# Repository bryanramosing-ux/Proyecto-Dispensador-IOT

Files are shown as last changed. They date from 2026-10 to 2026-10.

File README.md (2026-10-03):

# Dispensador inteligente de alimento para mascotas mediante IoT, visión artificial y energía solar

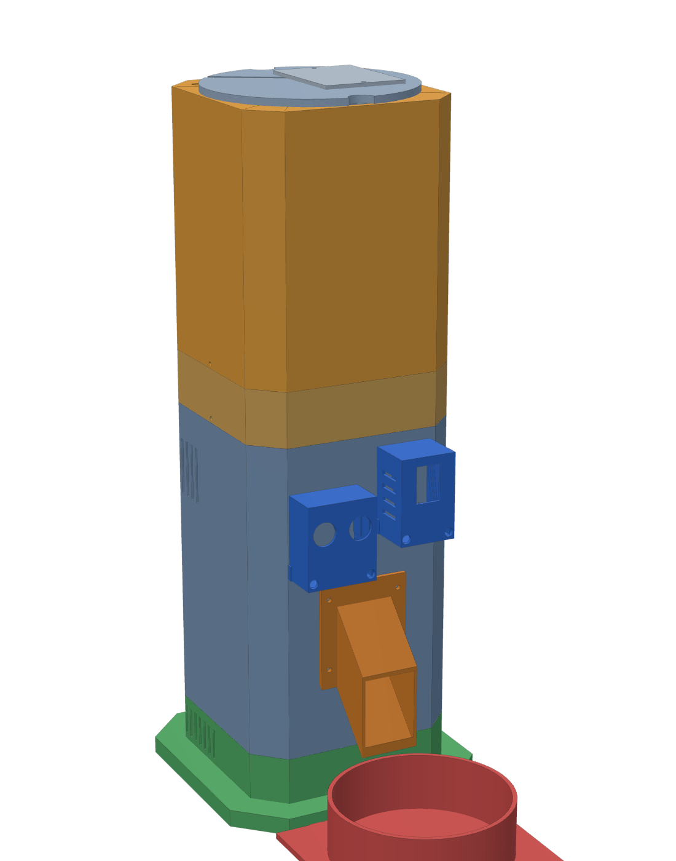
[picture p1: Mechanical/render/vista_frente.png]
Torre ensamblada


Proyecto universitario para feria de informática. Este repositorio contiene **todo** lo necesario para
construirlo y probarlo: firmware del ESP32 y de la ESP32-CAM, servidor de visión en Python + OpenCV,
22 piezas STL paramétricas listas para la **Elegoo Neptune 4 Plus**, [manual de armado](Documentation/manual_armado/Manual_de_Armado.md)
([PDF](Documentation/manual_armado/Manual_de_Armado.pdf)), un **[video de funcionamiento y armado](Documentation/video)**
(≈ 7 min, narrado y subtitulado), esquema eléctrico completo, cálculo energético, procedimientos de calibración y plan de
pruebas.

> **Cómo se elaboró (técnica ROL – TAREA – CONTEXTO).**
> **ROL:** equipo de ingeniería electrónica, sistemas embebidos/IoT, visión artificial, mecánica/diseño 3D,
> arquitectura de software y asesoría académica. **TAREA:** auditar el planteamiento inicial, corregirlo donde
> no era físicamente correcto y entregar un sistema construible. **CONTEXTO:** hardware principal fijado
> (ESP32 DevKit V1, ESP32-CAM, HC-SR04, MG995, panel solar ≈3 V/100 mA), identificación solo por visión
> artificial (1 = PERRO, 2 = GATO), torre modular impresa en 3D.
>
> **Regla de lectura:** todo valor marcado **PROVISIONAL** o **VERIFICAR** no es un dato de fábrica; se
> obtiene en la calibración. Los valores "típicos" se citan con su fuente y deben medirse.

> **Recomendaciones del profesor incorporadas (versión 2):**
> 1. **El panel solar va aparte**, en una **estación solar remota** (piezas 12a + 12b) que se coloca donde haya sol, a
>    3–5 m, unida al cajón de energía por un cable con conector **GX12**. La bandeja se orienta de 0° a 75° (§21, §31).
> 2. **Sensor ultrasónico dentro de la tolva:** un **segundo HC-SR04** en la tapa mide el nivel de alimento y el ESP32
>    envía una **alerta** al PC (panel web y, opcionalmente, notificación al celular con ntfy) cuando la comida se está
>    acabando (§18, §24, §25).
>
> **Versión 3 (dos preguntas más del profesor):**
> 3. **¿Wi-Fi o local?** El sistema funciona **de manera local**: los tres equipos se hablan dentro de una red local
>    (Wi-Fi es solo el medio) y **no usan Internet**; la foto no sale de la sala y se analiza en el PC. Comparación de
>    opciones, cómo armar una red propia para la feria y una herramienta para medir los tiempos reales en §13.5.
> 4. **Fotos en vez de grabar video:** la ESP32-CAM pasó a **modo foto** (no captura cuadros de forma continua) y,
>    cuando el HC-SR04 detecta a la mascota, se toma **una foto cada ~2 s** solo mientras esté delante, hasta
>    identificarla (máx. 5). Las fotos de la misma visita se combinan para no equivocarse (§11, §12, §24).
>
> Además: todas las piezas se verificaron para el volumen de la **Elegoo Neptune 4 Plus** (320 × 320 × 385 mm) con un
> [plan de impresión](Mechanical/plan_impresion.md) por placas, hay un [manual de armado paso a paso](Documentation/manual_armado/Manual_de_Armado.md)
> y un [esquema de conexiones completo](Documentation/wiring/esquema_conexiones.svg) con su
> [tabla punto a punto](Documentation/wiring/tabla_conexiones.md).

## Índice

1. [Resumen ejecutivo](#1-resumen-ejecutivo) · 2. [Objetivo general](#2-objetivo-general) · 3. [Objetivos específicos](#3-objetivos-específicos) · 4. [Componentes definitivos](#4-componentes-definitivos) · 5. [Componentes eliminados](#5-componentes-eliminados) · 6. [Función de cada componente](#6-función-de-cada-componente) · 7. [Arquitectura general](#7-arquitectura-general) · 8. [Flujo completo](#8-flujo-completo) · 9. [Diagrama de bloques](#9-diagrama-de-bloques) · 10. [Arquitectura ESP32](#10-arquitectura-esp32) · 11. [Arquitectura ESP32-CAM](#11-arquitectura-esp32-cam) · 12. [Arquitectura Python + OpenCV](#12-arquitectura-python--opencv) · 13. [Comunicación entre dispositivos](#13-comunicación-entre-dispositivos) · 14. [Esquema eléctrico](#14-esquema-eléctrico) · 15. [Tabla de conexiones pin por pin](#15-tabla-de-conexiones-pin-por-pin) · 16. [Alimentación eléctrica](#16-alimentación-eléctrica) · 17. [Análisis del MG995](#17-análisis-del-mg995) · 18. [Análisis del HC-SR04](#18-análisis-del-hc-sr04) · 19. [Análisis del ESP32](#19-análisis-del-esp32) · 20. [Análisis de la ESP32-CAM](#20-análisis-de-la-esp32-cam) · 21. [Análisis del sistema solar](#21-análisis-del-sistema-solar) · 22. [Dosificación](#22-dosificación) · 23. [Calibración](#23-calibración) · 24. [Máquina de estados](#24-máquina-de-estados) · 25. [Manejo de errores](#25-manejo-de-errores) · 26. [Seguridad](#26-seguridad) · 27. [Diseño mecánico](#27-diseño-mecánico) · 28. [Diseño de la torre](#28-diseño-de-la-torre) · 29. [Distribución física de los componentes](#29-distribución-física-de-los-componentes) · 30. [Recorrido del alimento](#30-recorrido-del-alimento) · 31. [Piezas STL necesarias](#31-piezas-stl-necesarias) · 32. [Recomendaciones de impresión 3D](#32-recomendaciones-de-impresión-3d) · 33. [Tecnologías utilizadas](#33-tecnologías-utilizadas) · 34. [Estructura del software](#34-estructura-del-software) · 35. [Estructura de archivos](#35-estructura-de-archivos) · 36. [Algoritmo](#36-algoritmo) · 37. [Código propuesto](#37-código-propuesto) · 38. [Plan de pruebas](#38-plan-de-pruebas) · 39. [Problemas posibles](#39-problemas-posibles) · 40. [Soluciones](#40-soluciones) · 41. [Lista de verificación](#41-lista-de-verificación) · 42. [Auditoría técnica final](#42-auditoría-técnica-final)

---

## 1. Resumen ejecutivo

El dispensador es una **torre modular de ≈ 49 cm** impresa en 3D. Cuando una mascota se acerca, el **HC-SR04**
la detecta; el **ESP32** pide una clasificación al **PC**, que descarga una foto de la **ESP32-CAM** por Wi-Fi y la
analiza con **Python + OpenCV** usando una red neuronal **MobileNetV2** ejecutada por `cv2.dnn`. El PC responde
`1 = PERRO`, `2 = GATO` o `0 = INDETERMINADO`. El ESP32 **decide** si corresponde dispensar (clase válida,
tiempo mínimo entre raciones, límite diario, batería y servo correctos, mascota todavía presente) y mueve el
**MG995**, que gira un **disco volumétrico**: cada ciclo entrega un volumen fijo de alimento que cae por un
**conducto cerrado** hasta el comedero. La electrónica está en compartimientos separados del alimento. Un **segundo
HC-SR04** en la tapa de la tolva mide cuánto alimento queda y el ESP32 **avisa** al PC (y al celular) cuando se está
acabando. El **panel solar** está en una **estación remota** orientable, donde haya sol, unida a la torre por un cable.

**La auditoría previa encontró errores en el planteamiento inicial que se corrigieron** (detalle en §7 y §42):

| # | Planteamiento inicial | Problema real | Corrección aplicada |
|---|---|---|---|
| 1 | El panel solar alimenta el sistema | Panel ≈ 0,3 W pico; el sistema consume ≈ 1,7 W **promedio** (picos de 20 W con el servo trabado). El panel aporta ≈ 1,7 % de la energía diaria al sol y ≈ 0,03 % en interior | Batería 2S Li-ion + BMS + convertidores. El panel queda como **subsistema de captación demostrativo** con medición en tiempo real; se dimensiona el panel que haría falta (≈ 14 W) |
| 2 | MG995 conectado al ESP32 | Consume 0,5–0,9 A moviéndose y ≈ 2,5 A bloqueado (no lo soporta ni un GPIO ni el regulador de 3,3 V) | Convertidor **exclusivo** de 6,0 V (≥ 3 A); el ESP32 solo da la señal; GND común |
| 3 | Batería conectada al servo | Una 2S llega a 8,4 V; el MG995 admite 4,8–7,2 V | Siempre a través del convertidor de 6,0 V |
| 4 | ECHO del HC-SR04 directo al ESP32 | ECHO sale a 5 V; el ESP32 admite como máximo 3,6 V | Divisor 1 kΩ / 2 kΩ → 3,33 V en GPIO34 |
| 5 | "OpenCV reconoce perros y gatos" | OpenCV no clasifica por sí solo | OpenCV procesa y ejecuta un **modelo entrenado** (MobileNetV2, ImageNet). Se suman las 118 razas de perro y los 5 gatos domésticos |
| 6 | Resultado solo 1 o 2 | Hace falta un valor para "no sé / imagen mala" | Se añade **0 = INDETERMINADO → no dispensar** (1 y 2 se mantienen exactos) |
| 7 | Capas apiladas: tolva → MG995 → ESP32-CAM → HC-SR04 → ESP32 → salida | El alimento atravesaría las capas de electrónica | Columna de alimento **cerrada** al frente, tabique, bahía electrónica atrás, sensores en cápsulas frontales, energía en la base |
| 8 | Sinfín como dosificador | Un sinfín necesita giro continuo; el MG995 estándar gira ≈ 180° y se traba con croquetas | **Disco volumétrico de un bolsillo** con vaivén de 100° (compatible con servo posicional) |
| 9 | "90° = 80 g" | No existe relación fija ángulo-gramos | Ración = **N ciclos**; gramos por ciclo medidos con balanza (procedimiento §23) |
| 10 | ESP32 recibe la imagen | Innecesario y costoso en RAM | El **PC pide la foto directamente a la cámara**; el ESP32 solo recibe el JSON |

**Qué está verificado y qué no.** Verificado en este repositorio (y de nuevo en cada `push` por GitHub
Actions, `.github/workflows/verificacion.yml`):

* **Firmware compilado con la cadena oficial de Espressif** (Arduino-ESP32 **2.0.17** y **3.0.7**, `--warnings all`,
  sin advertencias propias): ESP32 960 kB / 1 097 kB (73 % / 83 % de la flash), ESP32-CAM 847 kB / 1 023 kB.
* **Firmware del ESP32 ejecutado en el emulador QEMU de Espressif**: arranca, entra en la máquina de estados y
  responde a todos los comandos, incluido `NIVEL` (autoprueba de 14 puntos). El emulador encontró un error real que se
  corrigió (el botón BOOT mantenido borraba errores cada 50 ms).
* 26 escenarios de la máquina de estados en PC (5 del sensor de nivel; 2 de las fotos cada 2 s: ritmo, máximo de 5
  y que no se repita la consulta a la cámara); 29 pruebas del servicio de visión (extremo a extremo por HTTP, fotos de
  una misma visita, alertas, panel web y reenvío al celular); **modelo real** sobre 25 imágenes públicas: 9/9 perros, 5/5 gatos y 0
  errores peligrosos con 11 animales parecidos (lobo, coyote, dingo, zorros, hiena, puma, lince, tigre, guepardo) y un peluche.
* 45 comprobaciones geométricas (cero interferencias en 171 pares, recorrido del alimento continuo, cápsula del sensor
  de nivel fuera del alimento, bandeja solar libre de 0° a 75°, **las 22 piezas caben en la Neptune 4 Plus**) y la
  placa de control y el esquema se regeneran desde `config.h` (fallan si un pin no coincide).

**Pendiente de prueba física** (no se puede hacer sin el hardware): consumos reales, calibración de posiciones y
gramos, umbrales con la cámara instalada, Wi-Fi y cámara reales, comportamiento del panel. El plan de pruebas (§38)
cubre cada punto.

## 2. Objetivo general

Diseñar, construir y validar un dispensador automático de alimento para mascotas, con estructura de torre
modular impresa en 3D, que identifique por visión artificial si la mascota que se acerca es un perro o un gato y
entregue una ración calibrada solo cuando corresponda, integrando IoT (Wi-Fi/HTTP), visión artificial
(Python + OpenCV) y un subsistema de energía con captación solar analizado de forma realista.

## 3. Objetivos específicos

1. Detectar la aproximación de una mascota con el HC-SR04 de forma robusta (mediana, confirmación y rearmado).
2. Capturar imágenes con la ESP32-CAM y transmitirlas por Wi-Fi al PC bajo demanda.
3. Clasificar la imagen en Python + OpenCV como **1 = PERRO** o **2 = GATO**, devolviendo **0** si la confianza o
   la calidad de imagen no son suficientes.
4. Implementar en el ESP32 una máquina de estados que valide la decisión y gestione errores reales.
5. Accionar el MG995 con alimentación independiente y un mecanismo de dosificación repetible.
6. Garantizar un recorrido físico del alimento continuo y separado de la electrónica.
7. Diseñar una torre modular, desmontable e imprimible sin soportes.
8. Analizar la energía (consumo, picos, autonomía, aporte solar) sin afirmaciones imposibles.
9. Definir procedimientos de calibración y un plan de pruebas con criterios de aprobación.
10. Medir el nivel de alimento de la tolva con un segundo HC-SR04 y **avisar** cuando se esté por acabar (recomendación
    del profesor).
11. Separar la captación solar en una **estación remota** orientable, ubicada donde haya sol (recomendación del profesor).

## 4. Componentes definitivos

**Componentes funcionales principales (los únicos del proyecto):**

| Componente | Cant. | Papel |
|---|---|---|
| ESP32 DevKit V1 (ESP32-WROOM-32, 30 pines) | 1 | Controlador y actuador |
| ESP32-CAM AI-Thinker (OV2640) | 1 | Captura de imágenes |
| HC-SR04 (versión de 5 V) | **2** | n.º 1: detección de aproximación (frente) · n.º 2: **nivel de alimento en la tolva** (tapa) |
| Servomotor MG995 (versión **180°**, no la de giro continuo) | 1 | Accionamiento del dosificador |
| Panel solar ≈ 3 V / 100 mA (con cable) | 1 | Captación solar (demostrativa), en la **estación remota** |

**COMPONENTES AUXILIARES DE ALIMENTACIÓN** (no son "funcionales", pero sin ellos el sistema no es
eléctricamente posible; ver §16 y §21):

| Componente | Cant. | Por qué es necesario |
|---|---|---|
| Celdas Li-ion 18650 (marca/capacidad verificable) | 2 (o 4 para 2S2P) | Almacenamiento: el panel no puede alimentar el sistema en tiempo real |
| Portapilas 2S (2×18650 en serie) | 1 | Montaje seguro de las celdas |
| BMS 2S con balanceo, ≥ 5 A, puerto común | 1 | Protege contra sobrecarga, sobredescarga y cortocircuito |
| Cargador elevador USB-C 5 V → 2S (8,4 V CC/CV) | 1 | Carga principal desde un cargador USB |
| Elevador MT3608 (ajustable) | 1 | Eleva los ≈ 3 V del panel a 5 V para la entrada del cargador |
| Diodo Schottky 1N5817 | 1 | Evita que el circuito descargue hacia el panel |
| Convertidor reductor **Buck A** ≥ 3 A (p. ej. módulo XL4015) | 1 | 6,0 V **exclusivo** del MG995 |
| Convertidor reductor **Buck B** 2–3 A (p. ej. LM2596 o MP1584) | 1 | 5,0 V para ESP32, ESP32-CAM y HC-SR04 |
| Fusible 4 A lento + portafusible | 1 | Protección del cableado de batería |
| Interruptor basculante (≥ 6 A) | 1 | Corte general |

Lista de compras completa (con cantidades) en
[`Documentation/components/lista_materiales.csv`](Documentation/components/lista_materiales.csv) (se abre con Excel o
Google Sheets).

**Componentes pasivos y de montaje:** R1 1 kΩ, R2 2 kΩ (divisor ECHO de presencia); **R5 1 kΩ, R6 2 kΩ (divisor
ECHO del sensor de nivel)**; 330 Ω (serie señal servo); 10 kΩ (pull-down señal servo); 4 × 100 kΩ y 2 × 33 kΩ
(divisores de medición); 1 × 1000–2200 µF ≥ 10 V (servo); 3 × 470 µF ≥ 10 V (salida del Buck B, placa de control y
ESP32-CAM); 4 × 100 nF (3 en la placa de control junto a los ADC, 1 en la ESP32-CAM); placa perforada 90×70 mm; tiras
de pines hembra; conectores entre módulos (JST-XH o XT30); **conector GX12 de 2 pines (macho + hembra) y 3–5 m de cable
bipolar de exterior** para la estación solar; **cable de 4 hilos de ~120 cm** para el sensor de nivel; cable AWG 20
(potencia) y AWG 24 (señal); tornillería: 26 × M3×10, 6 × M3×12, 8 tuercas M3 (+ repuestos), 2 × M4×12 con tuerca y
arandela (pivote de la estación solar); adaptador USB-TTL 3,3 V o placa ESP32-CAM-MB (solo para programar la cámara);
PC/notebook con Wi-Fi; router o punto de acceso 2,4 GHz.

## 5. Componentes eliminados

No forman parte del sistema y **no se usan en ningún archivo**: RC522, RFID, NFC, tags NFC/RFID, sensor PIR,
cualquier otro sensor de movimiento, motor paso a paso, driver DRV8825 y cualquier otro actuador. La identificación
es **exclusivamente** por visión artificial.

## 6. Función de cada componente

| Componente | Qué hace en el sistema | Qué NO hace |
|---|---|---|
| ESP32 DevKit V1 | Lee el HC-SR04, confirma presencia, pide la clasificación al PC, **decide** si dispensar, genera el PWM del servo, mide tensiones, gestiona errores, expone `/status` | No procesa imágenes, no alimenta el servo |
| ESP32-CAM | Toma una foto JPEG cuando el PC la pide (`/capture`) | No clasifica, no se conecta por cable al ESP32 |
| HC-SR04 n.º 1 (presencia) | Mide distancia (ultrasonido 40 kHz) para saber si hay algo delante del comedero | No distingue perro, gato, persona u objeto |
| HC-SR04 n.º 2 (nivel) | Desde la tapa, mide la distancia a la superficie del alimento → % de volumen restante → alertas | No mide gramos (depende de la densidad del alimento) |
| MG995 | Gira el disco dosificador entre las posiciones LLENADO, DESCARGA y CERRADO | No "sabe" cuántos gramos entrega; no informa su posición |
| Panel solar (estación remota) | Capta energía (aporte pequeño) donde haya sol y su tensión se mide como indicador de irradiancia | No alimenta el sistema ni el servo |
| PC + Python + OpenCV + modelo | Descarga la foto, verifica su calidad, ejecuta la red neuronal y devuelve 1/2/0; recibe las alertas de nivel y las muestra (panel web) o las reenvía al celular | No controla el servo ni decide las raciones |
| Batería + BMS + convertidores | Almacenan energía y entregan 6,0 V (servo) y 5,0 V (lógica) estables | — |

## 7. Arquitectura general

### 7.1 Auditoría de la arquitectura propuesta

La cadena conceptual MASCOTA → HC-SR04 → ESP32 → ESP32-CAM → Wi-Fi → PC → OpenCV → 1/2 → ESP32 → MG995 →
dosificador → conducto → comedero es **correcta en sus responsabilidades**, pero se precisan tres puntos:

1. **Quién transporta la imagen.** Si el ESP32 recibiera la foto para reenviarla al PC, necesitaría decenas de kB
   de RAM y el doble de tráfico. **Mejor:** el ESP32 hace una sola petición `GET /classify` al PC; el PC (cliente)
   descarga la foto directamente de la ESP32-CAM (servidor) y contesta al ESP32 en la misma respuesta HTTP.
2. **No hay cables de datos entre ESP32 y ESP32-CAM.** Todo es por Wi-Fi; solo comparten la alimentación de 5 V y GND.
   Así se evita usar los pocos GPIO libres de la ESP32-CAM (casi todos están ocupados por la cámara).
3. **La decisión final es del ESP32**, no del PC: el PC solo informa qué ve. El ESP32 aplica reglas de seguridad
   (cooldown, límite diario, batería, servo, mascota todavía presente). Si el PC falla, el sistema **no dispensa**.

### 7.2 Arquitectura definitiva

```
                         Wi-Fi 2,4 GHz (router o punto de acceso)
        ┌───────────────────────────────┬──────────────────────────────────┐
        │                               │                                  │
┌───────┴────────┐  1) GET /classify  ┌─┴───────────────────────┐  2) GET /capture ┌──────────────┐
│ ESP32 DevKit V1│ ─────────────────▶ │ PC / NOTEBOOK           │ ───────────────▶ │  ESP32-CAM   │
│ 192.168.1.52   │                    │ 192.168.1.50:8000       │ ◀─────────────── │ 192.168.1.51 │
│ máquina estados│ ◀───────────────── │ Python + OpenCV (dnn)   │   JPEG 640×480   │ solo captura │
│                │ 3) {"clase":1|2|0} │ + MobileNetV2 (ONNX)    │                  └──────────────┘
└──┬─────┬───┬───┘                    └─────────────────────────┘
   │     │   │ PWM 50 Hz (solo señal)
   │     │   └──────────────▶ MG995 ◀── 6,0 V (Buck A) ── disco dosificador ── conducto ── comedero
   │     ├── TRIG/ECHO(divisor) ── HC-SR04 n.º 1 (presencia, 5 V)
   │     └── TRIG2/ECHO2(divisor) ── HC-SR04 n.º 2 (nivel de la tolva) ──▶ 4) POST /alerta al PC ──▶ panel web / ntfy
   └── ADC: batería, riel 6 V, panel (estación solar remota ── cable 3–5 m ── GX12 ── cajón de energía)
```

## 8. Flujo completo

```mermaid
flowchart TD
  A([INICIO]) --> B[Inicializar ESP32: GPIO, ADC, LED, botón]
  B --> C[Inicializar HC-SR04: TRIG salida, ECHO entrada]
  C --> D[Inicializar MG995: PWM 50 Hz, disco a CERRADO, liberar]
  D --> E{Conectar Wi-Fi}
  E -- no --> EW[ERROR_WIFI: reintento cada 5 s, reinicio a los 5 min]
  EW --> E
  E -- sí --> F[ESPERANDO]
  F --> NV[Cada 60 s: nivel de la tolva, HC-SR04 n.º 2]
  NV --> NA{¿Bajo 20 % del volumen, 3 lecturas?}
  NA -- sí --> AL[POST /alerta COMIDA_BAJA al PC: panel web y celular] --> G
  NA -- no --> G
  F --> G[Leer distancia: mediana de 3 disparos]
  G --> H{¿Batería >= 6,8 V?}
  H -- no --> EA[ERROR_ALIMENTACION: no dispensar hasta >= 7,0 V] --> F
  H -- sí --> I{¿3 lecturas seguidas entre 3 y 35 cm, zona rearmada y sin cooldown?}
  I -- no, demasiado lejos / tapado --> F
  I -- sí --> J[DETECTADO]
  J --> K{¿ESP32-CAM responde /status?}
  K -- no, 2 veces --> EC[ERROR_CAMARA: reintento cada 30 s] --> F
  K -- sí --> L[PROCESANDO: GET /classify al PC, timeout 10 s]
  L --> M[PC: 1 foto nueva, calidad, OpenCV + modelo, se une con las fotos de la visita]
  M --> N{¿Respuesta válida?}
  N -- timeout / JSON inválido --> ECL[ERROR_CLASIFICACION: reintento 30 s] --> F
  N -- 502 cámara --> EC
  N -- clase 0: borrosa, oscura, incierta, sin mascota --> O{¿Menos de 5 fotos y sigue presente?}
  O -- sí, otra foto tras 2 s --> L
  O -- no --> P[No dispensar, esperar zona libre] --> F
  N -- 1 PERRO / 2 GATO --> Q{¿Clase habilitada, cooldown cumplido, límite diario OK, tolva no agotada?}
  Q -- no --> P
  Q -- sí --> R{¿La mascota sigue delante?}
  R -- no, se fue --> P
  R -- sí --> S{¿Riel de 6 V presente?}
  S -- no --> ES[ERROR_SERVO: bloqueante] 
  S -- sí --> T[DOSIFICANDO: N ciclos llenar → descargar]
  T --> U{¿Caída sostenida del riel = atasco?}
  U -- sí, tras 2 retrocesos --> EM[ERROR_MECANISMO: bloqueante, liberar servo]
  U -- no --> V[Alimento cae por el conducto al comedero]
  V --> W[FINALIZADO: registrar ración, bloqueo temporal]
  W --> F
  ES -.botón BOOT 2 s / RESET.-> F
  EM -.botón BOOT 2 s / RESET.-> F
```

**Situaciones reales cubiertas:** mascota demasiado lejos (no supera el umbral), mascota que se va (se comprueba
antes de dispensar y antes de reintentar), imagen borrosa/oscura/sobreexpuesta/ inválida (clase 0), clasificación
incierta o ambigua (clase 0), Wi-Fi caído (ERROR_WIFI, reconexión y reinicio), ESP32-CAM sin respuesta
(ERROR_CAMARA), PC sin respuesta (ERROR_CLASIFICACION), servo sin alimentación (ERROR_SERVO), atasco
(ERROR_MECANISMO), batería baja (ERROR_ALIMENTACION), panel insuficiente (no bloquea: la batería manda; se informa
en `/status`), activaciones repetidas (cooldown global, cooldown por clase, límite diario y rearmado por zona libre),
**comida por acabarse** (alerta COMIDA_BAJA), **tolva vacía** (COMIDA_AGOTADA: no gira en vacío), **sensor de nivel
sin eco** (aviso, no bloquea) y **PC que no recibe la alerta** (reenvío cada 30 s).

## 9. Diagrama de bloques

```
                 MASCOTA
                    │ (ultrasonido)
                    ▼
     HC-SR04 n.º 2 (tolva) ──TRIG2/ECHO2 (divisor 1k/2k)──┐  nivel → alertas (POST /alerta)
                 HC-SR04 ──TRIG/ECHO (divisor 1k/2k)──┤
                                                      ▼
                                                   ESP32 ◀──────────────────────────────┐
                                                      │                                 │
                         ┌────────────────────────────┴───────────────┐                 │
                         │ Wi-Fi: GET /classify                       │ PWM (solo señal)│
                         ▼                                            ▼                 │
                  PC / NOTEBOOK ──GET /capture──▶ ESP32-CAM         MG995 ◀── 6,0 V     │
                  Python + OpenCV ◀──── JPEG ────                     │                 │
                  + MobileNetV2                                       ▼                 │
                         │                                   DISCO DOSIFICADOR          │
                         ▼                                            │                 │
                  1 = PERRO / 2 = GATO / 0 = no dispensar             ▼                 │
                         │                                     CONDUCTO CERRADO         │
                         └──────────────── JSON ──────────────────────┼─────────────────┘
                                                                      ▼
                                                                  COMEDERO

     ESTACIÓN SOLAR REMOTA: PANEL ─(cable 3–5 m, GX12)─▶ D1 ─▶ ELEVADOR 5 V ─▶ CARGADOR 2S ─▶ BMS + 2×18650 ─▶ F1 ─▶ S1 ─┬─▶ BUCK A 6,0 V ─▶ MG995
     USB-C 5 V ────────────────────────────────────────────────────┘                                   └─▶ BUCK B 5,0 V ─▶ ESP32, ESP32-CAM, 2 × HC-SR04
```

## 10. Arquitectura ESP32

* **Entorno:** C++ con el núcleo Arduino-ESP32 (2.x o 3.x); se abre igual en **Arduino IDE** y en **PlatformIO**
  (`ESP32/platformio.ini` apunta a la carpeta del sketch). Biblioteca externa: **ArduinoJson 7**.
* **Módulos** (cada uno con una responsabilidad):

| Módulo | Responsabilidad | Hardware |
|---|---|---|
| `Controlador` | Máquina de estados y reglas de decisión. **No incluye `Arduino.h`**: se prueba en PC | Ninguno (usa la interfaz `Hardware`) |
| `Ultrasonico` | Disparo de 10 µs, `pulseIn` con timeout 30 ms, mediana de N, ≥ 60 ms entre disparos | GPIO26, GPIO34 |
| `Dosificador` | PWM LEDC 50 Hz/16 bits, rampa (10 µs cada 10 ms), ciclo llenar/descargar, agitación, retroceso ante atasco, liberación del servo | GPIO25 |
| `Energia` | `analogReadMilliVolts` (calibración eFuse), promedio de 16 muestras, factores de divisor | GPIO35, 32, 33 |
| `NivelTolva` + `NivelGeometria.h` | HC-SR04 n.º 2: mediana de 5, calibración VACIO/LLENO guardada en la flash (NVS), altura → **% de volumen** con la tabla calculada del embudo | GPIO19, GPIO21 |
| `Red` | Wi-Fi con IP fija, reconexión, cliente HTTP con timeouts, servidor `/status`, `POST /alerta` al PC | Wi-Fi |
| `Dispensador_ESP32.ino` | Une los módulos (`HardwareReal`), lazo de 50 ms, comandos serie, LED | GPIO2, GPIO0 |

* **Patrón:** la máquina de estados depende de una interfaz abstracta `Hardware`; en el ESP32 la implementa
  `HardwareReal` y en las pruebas de PC un `FakeHW`. Así se probaron 26 escenarios sin placa.
* **Sin bloqueos largos:** el lazo corre cada 50 ms; las únicas esperas largas son la petición HTTP (máx. 10 s,
  con timeout) y la dosis (el servo debe completar el ciclo).

## 11. Arquitectura ESP32-CAM

* Firmware mínimo (`ESP32_CAM/Camara_ESP32CAM`): inicializa la cámara (pines fijos AI-Thinker), se conecta al Wi-Fi
  con IP fija y ofrece dos rutas HTTP: `GET /capture` (JPEG nuevo) y `GET /status` (diagnóstico).
* **Modo foto (idea del profesor: no grabar video):** un solo búfer en PSRAM con `CAMERA_GRAB_WHEN_EMPTY`; así el
  controlador **no captura cuadros de forma continua**: toma uno cuando el PC pide `/capture`. El sensor queda encendido,
  de modo que la exposición automática ya está ajustada. Como el búfer puede conservar la foto anterior (de segundos o
  minutos atrás), se descarta y se toma una nueva: siempre se entrega una foto **actual**. VGA 640×480, JPEG calidad 12.
  Con nadie delante no se saca ni se envía ninguna foto.
* **Robustez:** reintento de inicialización de la cámara cada 10 s si falla; reconexión Wi-Fi cada 5 s; reinicio a
  los 2 min sin red; LED rojo (GPIO33) encendido si hay problema; flash desactivado por defecto.
* **Programación:** no tiene USB: placa ESP32-CAM-MB o adaptador USB-TTL de 3,3 V con GPIO0 a GND al cargar.

## 12. Arquitectura Python + OpenCV

Responsabilidades separadas (§32 de la consigna):

| Elemento | Responsabilidad |
|---|---|
| **ESP32-CAM** | Captura (y nada más) |
| **Python** (`servidor_vision.py`) | Ejecuta el programa en el PC: servidor HTTP, descarga de fotos, registro |
| **OpenCV** (`clasificador.py`) | `cv2.imdecode` (valida el JPEG), brillo medio, **varianza del Laplaciano** (nitidez), **CLAHE** (contraste en interiores), `cv2.dnn.blobFromImage` (224×224, RGB, escala) y **ejecución de la red con `cv2.dnn`** |
| **Modelo** MobileNetV2 (ONNX Model Zoo, ImageNet-1k, Apache-2.0, 14 MB) | Interpreta la imagen: 1000 probabilidades |
| **Regla de decisión** (`decidir`) | P(perro) = Σ índices 151–268 (118 razas); P(gato) = Σ índices 281–285 (gatos domésticos) |
| **Alertas** (`alertas.py`) | Recibe `POST /alerta` del ESP32 (nivel de la tolva), guarda las últimas, las muestra en el **panel web** (`GET /`) y, si se configura un tema de **ntfy**, las reenvía al celular |
| **ESP32** | Control y actuación |

**Por qué este modelo y no uno en la ESP32-CAM:** MobileNetV2 necesita ≈ 14 MB de pesos y ≈ 300 millones de
operaciones por imagen; la ESP32-CAM tiene 4 MB de PSRAM y 520 kB de SRAM, por lo que **no es adecuada** para
este modelo. Modelos diminutos en la ESP32 (p. ej. TinyML) exigirían entrenar uno propio y ofrecerían menor
precisión; la arquitectura híbrida Edge (captura) / PC (inferencia) es la más realista para el prototipo.

**Regla de decisión (valores PROVISIONALES, se ajustan con `probar_imagenes.py --barrido`):**

```
si P(perro)+P(gato) < 0,50            → 0  (SIN_MASCOTA)
si max(P(perro), P(gato)) < 0,60      → 0  (BAJA_CONFIANZA)
si |P(perro) − P(gato)| < 0,30        → 0  (AMBIGUO)
si no                                 → 1 si P(perro) > P(gato), si no 2
```

Antes del modelo, cada foto pasa un **control de calidad**: JPEG decodificable y ≥ 160×120 (si no,
`IMAGEN_INVALIDA`); brillo medio entre 35 y 225 (`IMAGEN_OSCURA` / `IMAGEN_SOBREEXPUESTA`); varianza del
Laplaciano ≥ 40 (`IMAGEN_BORROSA`).

**Fotos en vez de video (idea del profesor).** Cada pedido del ESP32 es **una** foto nueva. Si con ella no alcanza
para decidir (clase 0) y la mascota sigue delante, el ESP32 pide otra **cada ~2 s**, como máximo 5 por visita (≈ 10 s).
El PC **combina las fotos de la misma visita en las que se ve un animal** (las de los últimos 5 s, máximo 3): tomadas con
2 s de diferencia son más independientes que dos cuadros seguidos, así que una foto movida no decide sola y un perro y
un gato en la misma visita dan `AMBIGUO` → no se dispensa. Una foto sin animal (la mascota todavía entrando al cuadro)
no se mezcla. Cuando se decide PERRO o GATO, la visita termina y se empieza de cero. El panel web muestra la última
foto analizada, el resultado, el tiempo en ms y cuántas fotos de la visita se usaron.

**Resultado obtenido en este repositorio** (modelo real; `tests/descargar_imagenes_prueba.py` +
`tests/test_modelo_real.py`):

| Grupo | Imágenes | Resultado |
|---|---|---|
| Perros (chihuahua, beagle, fox terrier, golden, labrador, pastor alemán, husky, pug, caniche) | 9 | 9 × **PERRO** (P(perro) 0,66–1,00) |
| Gatos (atigrado, tiger cat, persa, siamés, egipcio) | 5 | 5 × **GATO** (P(gato) 0,74–1,00) |
| Parecidos: lobo, coyote, dingo, zorro ártico, hiena, puma, lince, tigre, guepardo, peluche, persona | 11 | 11 × **0** (`SIN_MASCOTA`; el tigre llega a P(gato) = 0,38, por debajo del umbral) |
| Zorro rojo (foto muy oscura) | 1 | **0** (`IMAGEN_OSCURA`: lo descarta el control de calidad) |

Cero decisiones peligrosas. **Aviso honesto:** son imágenes de ImageNet, el mismo conjunto con el que se entrenó el
modelo, por lo que el resultado es optimista. **No reemplaza la calibración con fotos de la cámara instalada** (§23.5).

## 13. Comunicación entre dispositivos

### 13.1 Selección del protocolo

| Opción | Ventajas | Desventajas | Decisión |
|---|---|---|---|
| **HTTP/REST** | Nativo en ESP32 (`HTTPClient`, `WebServer`) y Python (biblioteca estándar); se prueba con navegador o `curl`; petición-respuesta encaja con "pregunta → resultado" | Algo más de cabecera por mensaje | **Elegido** |
| TCP crudo | Mínimo | Hay que inventar el formato, el enmarcado y los errores | Descartado |
| MQTT | Bueno para muchos dispositivos y eventos | Requiere un *broker* adicional (Mosquitto) y no está pensado para transportar imágenes en una petición-respuesta | Innecesario para 3 equipos |
| WebSocket | Bidireccional | Complejidad sin beneficio aquí | Descartado |

### 13.2 Direcciones y roles

| Equipo | IP (configurable) | Cliente de | Servidor de |
|---|---|---|---|
| ESP32 | 192.168.1.52 (`config.h`) | PC (`/classify`, `/status`, `/alerta`), cámara (`/status`) | `/status` (puerto 80) |
| ESP32-CAM | 192.168.1.51 (`config.h` de la cámara) | — | `/capture`, `/status` (puerto 80) |
| PC | 192.168.1.50 (fijar por DHCP reservado o IP manual) | Cámara (`/capture`, `/status`), ESP32 (`/status`, para el panel), ntfy.sh (opcional) | `/classify`, `/status`, `/alerta`, `/`, `/panel.json`, `/ultima.jpg` (puerto 8000) |

Requisitos de red: **2,4 GHz** (el ESP32 no usa 5 GHz), **WPA2-Personal** (las redes con portal cautivo o
WPA2-Enterprise de las universidades no sirven). Para la feria se recomienda un router propio o el punto de acceso
del celular, ajustando las tres IP a su subred.

### 13.3 API (solo los endpoints que realmente se usan)

| Equipo | Método y URL | Envía | Respuesta | Errores | Timeout |
|---|---|---|---|---|---|
| ESP32-CAM | `GET http://192.168.1.51/capture` | — | `200 image/jpeg` (VGA; decenas de kB según la escena) | `503` cámara no inicializada / fallo de captura | El PC espera 3 s por foto |
| ESP32-CAM | `GET http://192.168.1.51/status` | — | `200 {"camara":true,"psram":true,"fotos_ok":12,"fotos_fallidas":0,"rssi":-58,"heap":..,"uptime_s":..}` | `503` si la cámara falló | ESP32: 2 s |
| PC | `GET http://192.168.1.50:8000/classify?dist=24` | `dist` = distancia en cm (solo registro) | `200 {"clase":1,"etiqueta":"PERRO","confianza":0.93,"motivo":"OK","p_perro":0.93,"p_gato":0.01,"fotos_validas":1,"fotos_visita":2,"ms":420}` | `200` con `"clase":0` y `motivo` ∈ {`BAJA_CONFIANZA`,`AMBIGUO`,`SIN_MASCOTA`,`IMAGEN_BORROSA`,`IMAGEN_OSCURA`,`IMAGEN_SOBREEXPUESTA`,`IMAGEN_INVALIDA`}; `502 {"clase":0,"motivo":"CAMARA_NO_RESPONDE"}`; `500 {"clase":0,"motivo":"ERROR_INTERNO"}` | ESP32: conexión 2 s, respuesta 10 s |
| PC | `GET http://192.168.1.50:8000/status` | — | Estado del servidor, versión de OpenCV, modelo, estado de la cámara, última clasificación y umbrales | — | ESP32: 2 s |
| PC | `POST http://192.168.1.50:8000/alerta` | `{"tipo":"COMIDA_BAJA","nivel":18}` (tipo ∈ {`COMIDA_BAJA`,`COMIDA_AGOTADA`,`COMIDA_REPUESTA`,`SENSOR_NIVEL_SIN_LECTURA`}) | `200 {"ok":true,"alerta":{...,"mensaje":"La comida del dispensador se está acabando (nivel ~18 %). Recargue la tolva."}}` | `400` tipo desconocido o JSON inválido | ESP32: 2 s; si falla, reenvío cada 30 s |
| PC | `GET http://192.168.1.50:8000/` y `/panel.json` | — | Panel web (se actualiza cada 5 s): barra de nivel de la tolva, estado del ESP32, alertas, últimas clasificaciones y la última foto analizada | Si el ESP32 no responde, el panel lo indica | PC → ESP32: 1 s |
| PC | `GET http://192.168.1.50:8000/ultima.jpg` | — | `200 image/jpeg`: la última foto que analizó el PC | `404` si todavía no hay fotos | — |
| ESP32 | `GET http://192.168.1.52/status` | — | `{"estado":"ESPERANDO","distancia_cm":48.2,"ultima_clase":2,...,"v_bateria":7.61,"v_servo":6.02,"v_panel":2.85,"nivel_tolva":64,"alerta_tolva":"NINGUNA","alerta_pendiente":false,"rssi":-60}` | — | — |

**Endpoints que NO existen a propósito:** `/feed` (un "dar comida" remoto permitiría sobrealimentar desde la red;
la dosis manual solo existe por cable USB, comando `CICLO`) y `/result` (el resultado viaja en la misma respuesta de
`/classify`; un endpoint aparte añadiría estado compartido y condiciones de carrera).

### 13.4 Secuencia

```mermaid
sequenceDiagram
  participant E as ESP32
  participant P as PC (Python + OpenCV)
  participant C as ESP32-CAM
  E->>C: GET /status (2 s, solo antes de la primera foto)
  C-->>E: 200 {"camara":true}
  loop una foto cada ~2 s mientras la mascota siga delante (máx. 5)
    E->>P: GET /classify?dist=24 (10 s)
    P->>C: GET /capture (3 s)
    C-->>P: 200 image/jpeg (foto nueva)
    P->>P: calidad + CLAHE + blob + cv2.dnn + fotos de la visita + decisión
    P-->>E: 200 {"clase":0|1|2,...}
  end
  E->>E: con 1 o 2: validar reglas y mover MG995
  Note over E: cada 60 s en ESPERANDO: nivel de la tolva
  E->>P: POST /alerta {"tipo":"COMIDA_BAJA","nivel":18}
  P-->>E: 200 {"ok":true}
  P->>P: panel web + ntfy (celular)
```

**Reconexión:** ESP32 y cámara reintentan el Wi-Fi cada 5 s (`WiFi.reconnect()`); el ESP32 se reinicia tras 5 min
sin red y la cámara tras 2 min. El PC no guarda conexiones abiertas (`Connection: close`), así que tolera reinicios.

### 13.5 ¿Wi-Fi o local? (pregunta del profesor)

**Respuesta corta: el dispensador ya funciona de manera local.** Los tres equipos (ESP32, ESP32-CAM y PC) se comunican
dentro de una **red local**; el Wi-Fi es solo el medio (el "cable sin cable") de esa red. **No se usa Internet:** la foto
va de la cámara al PC que está en la misma sala, se analiza ahí y la respuesta vuelve al ESP32. Lo único que sale a
Internet es el aviso **opcional** al celular (ntfy); el panel web funciona sin él.

| Opción | Dónde se analiza la foto | ¿Internet? | Rapidez | Consumo y dependencias | Decisión |
|---|---|---|---|---|---|
| En la nube (servicio en Internet) | Servidor remoto | Sí | Cada foto viaja por Internet: suma el retardo de la conexión, que varía | Datos, ancho de banda y depender de un servicio externo; las fotos salen de la casa | Descartada |
| **Red local (este diseño)** | PC en la misma red | **No** | La foto viaja solo por la red local; el análisis tardó ≈ 20 ms en el PC de desarrollo (`medir_red.py`) | Solo la red local; el PC ya está | **Elegida** |
| Todo dentro de la ESP32-CAM | La propia cámara | No | Sin envío de la foto | Menor (no haría falta el PC) | No es posible con este modelo: MobileNetV2 ocupa 14 MB y la ESP32-CAM tiene 4 MB de PSRAM y 520 kB de RAM. Habría que entrenar un modelo diminuto propio (TinyML), con menos precisión: mejora futura |
| Cable entre ESP32 y ESP32-CAM | — | No | — | — | La ESP32-CAM casi no tiene GPIO libres (§20) y la foto igual tiene que llegar a quien la analiza |

**Red local propia para la feria** (para no depender del Wi-Fi del lugar, que en las universidades suele ser
WPA2-Enterprise o tener portal cautivo, §13.2): un router pequeño **o el punto de acceso del celular con los datos móviles
apagados** — los equipos solo necesitan que la red exista, no que tenga Internet.

1. Crear la red: 2,4 GHz, WPA2-Personal, nombre y clave en `secrets.h` del ESP32 y de la cámara.
2. Conectar el PC y ver su subred (`ipconfig` en Windows, `ip a` en Linux), por ejemplo `192.168.43.x`.
3. Poner esa subred en `ESP32/Dispensador_ESP32/config.h` (`IP_ESP32`, `IP_GATEWAY`, `URL_PC`, `URL_CAMARA`), en
   `ESP32_CAM/Camara_ESP32CAM/config.h` y al arrancar el servidor (`--camara`, `--esp32`).
4. Dejar `NTFY_TOPICO` vacío: todo queda dentro de la red local.

Se evaluó también que el propio ESP32 cree la red (modo punto de acceso): elimina el router, pero el ESP32, que es el
que controla el servo, pasaría a retransmitir todas las fotos entre la cámara y el PC; por eso se prefiere un router o
el celular.

**Medir los tiempos reales para presentarlos** (en la red de la feria):

```bash
cd OpenCV
python medir_red.py --clasificar      # ida y vuelta al ESP32 y a la cámara, 1 foto, análisis y /classify completo
```

En el PC de desarrollo, con la cámara simulada en el mismo equipo, el análisis (OpenCV + MobileNetV2) tardó ≈ 20 ms y
`/classify` completo ≈ 30 ms; en la red Wi-Fi real se suma el envío de la foto, que es justamente lo que mide el script.

## 14. Esquema eléctrico

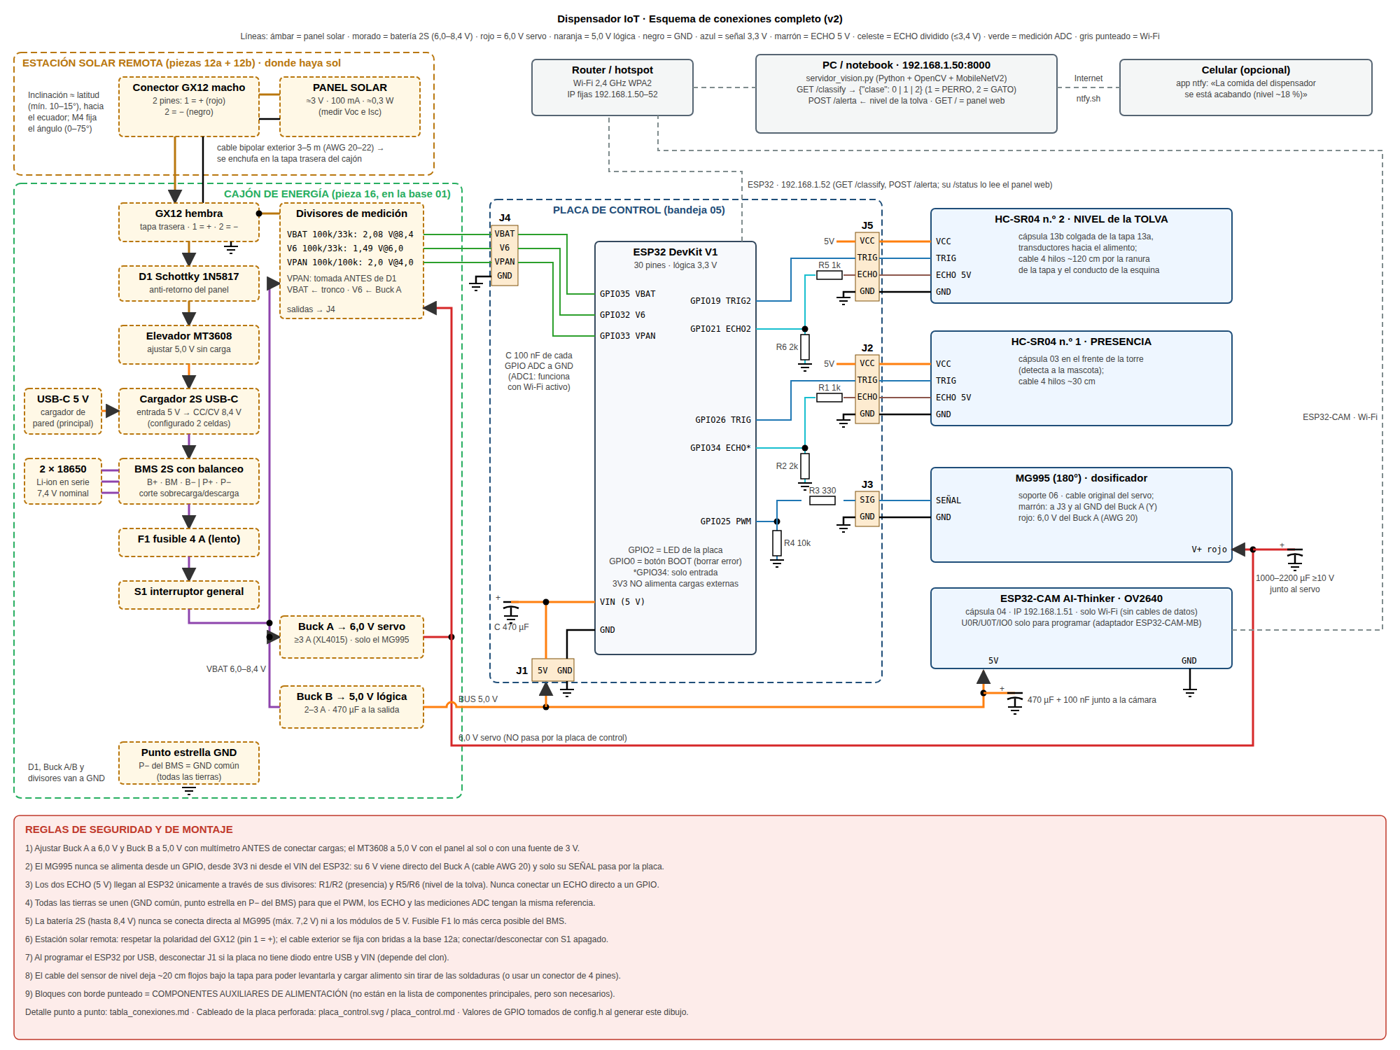
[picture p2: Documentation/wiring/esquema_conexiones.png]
Esquema de conexiones


Esquema **completo** de todos los componentes (estación solar remota, cajón de energía, placa de control con J1–J5,
los dos HC-SR04, MG995, ESP32-CAM, PC, router y celular): [`esquema_conexiones.svg`](Documentation/wiring/esquema_conexiones.svg).
Lo genera [`generar_esquema.py`](Documentation/wiring/generar_esquema.py) **leyendo los GPIO de `config.h`**, así que no
puede quedar desactualizado. Conexión por conexión (de dónde a dónde, sección del cable, recorrido por la torre y
comprobaciones antes de energizar): [`tabla_conexiones.md`](Documentation/wiring/tabla_conexiones.md).

```
                 ┌──────────────────────────────┐
     5,0 V ──────┤ VIN                     GPIO26├──────────────────────────── TRIG  HC-SR04
   (Buck B)      │                               │            ┌── R1 1 kΩ ──── ECHO  HC-SR04 (5 V)
                 │                         GPIO34├────────────┤
                 │      ESP32 DevKit V1          │            └── R2 2 kΩ ──── GND        (≈3,3 V en GPIO34)
                 │                         GPIO19├──────────────────────────── TRIG  HC-SR04 n.º 2 (tolva)
                 │                               │            ┌── R5 1 kΩ ──── ECHO  HC-SR04 n.º 2 (5 V)
                 │                         GPIO21├────────────┤
                 │                               │            └── R6 2 kΩ ──── GND        (≈3,3 V en GPIO21)
                 │                         GPIO25├── 330 Ω ─────────────────── SEÑAL MG995
                 │                               │   └── 10 kΩ ── GND (pull-down: servo quieto al arrancar)
  divisor VBAT ──┤ GPIO35                        │
  divisor 6 V  ──┤ GPIO32                    GND ├──────────┬──── GND COMÚN (punto estrella)
  divisor panel──┤ GPIO33                        │          │
                 └──────────────────────────────┘          │
                          │ Wi-Fi                           │
                          ▼                                 │
                 ┌──────────────────┐                       │
     5,0 V ──────┤ 5V  ESP32-CAM    │ (470 µF + 100 nF)     │
                 │ GND ─────────────┼───────────────────────┤
                 └──────────────────┘                       │
                 ┌──────────────────┐                       │
     6,0 V ──────┤ V+ (rojo) MG995  │ (1000–2200 µF)        │
   (Buck A)      │ GND (marrón) ────┼───────────────────────┤
                 │ SEÑAL ◀ ESP32    │                       │
                 └──────────────────┘                       │
                 ┌──────────────────┐                       │
     5,0 V ──────┤ VCC  HC-SR04 ×2  │                       │
                 │ GND ─────────────┼───────────────────────┘
                 │ TRIG ◀ GPIO26/19 │
                 │ ECHO ▶ divisores │
                 └──────────────────┘
```

### Placa de control (placa perforada 90×70 mm)

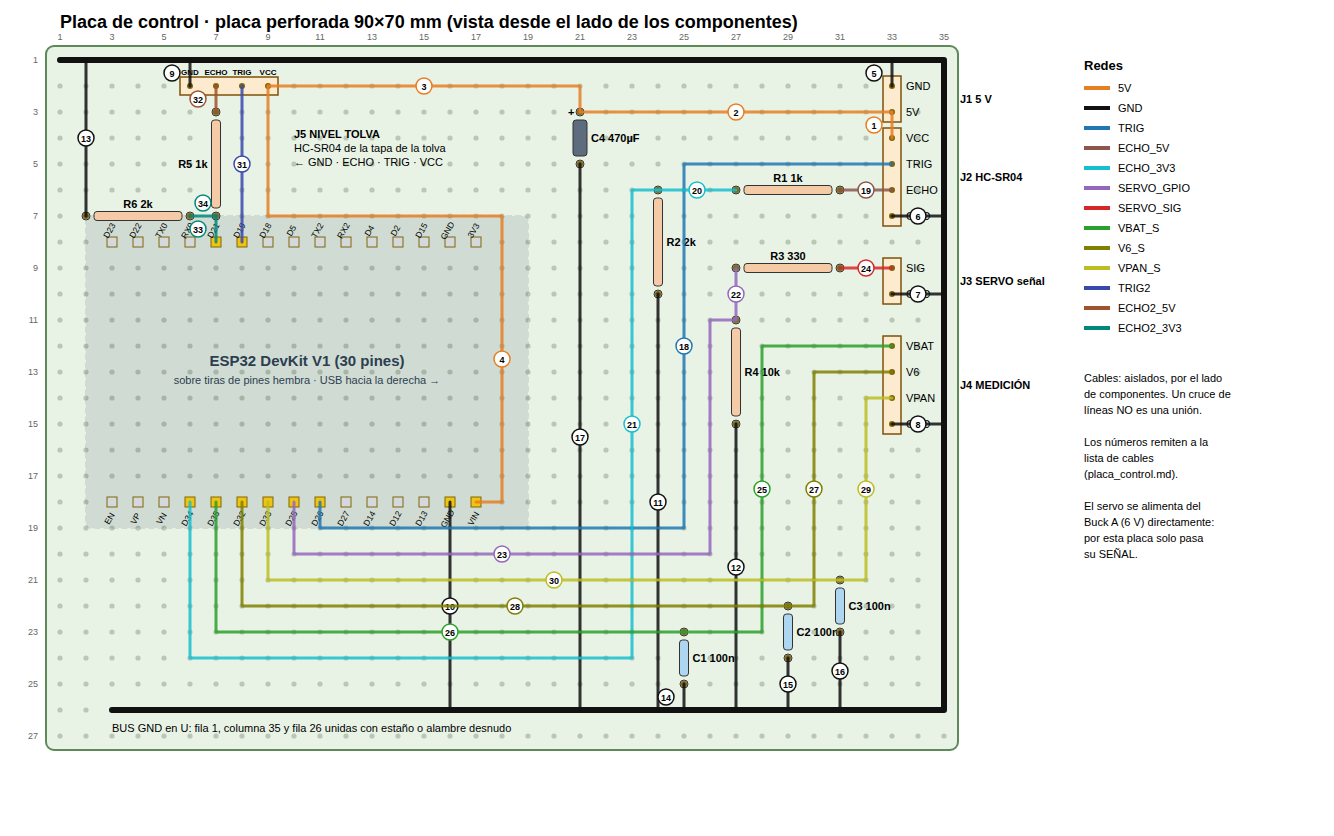
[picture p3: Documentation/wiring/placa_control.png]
Placa de control


Disposición de soldadura con 34 cables numerados y su lista paso a paso en
[`Documentation/wiring/placa_control.md`](Documentation/wiring/placa_control.md). La genera
[`generar_placa_control.py`](Documentation/wiring/generar_placa_control.py), que además **verifica** que cada red quede
unida, que ningún cable pase sobre un agujero ajeno, que los GPIO coincidan con `config.h`, que no se use ningún pin
prohibido y que los dos divisores dejen ≤ 3,4 V en GPIO34 y GPIO21 (esta comprobación corre en GitHub Actions). El
conector **J5** del sensor de nivel está en el borde superior izquierdo, junto a GPIO19/21 de la otra fila de pines:
sus cables son cortos y no cruzan ningún otro. El ESP32 va sobre tiras
de pines **hembra** (se retira para programarlo o reemplazarlo); el servo **no** recibe alimentación por esta placa,
solo su señal.

**Correcciones respecto del esquema sugerido:** el MG995 no se alimenta desde el ESP32 sino desde un convertidor
de 6,0 V propio; la línea ECHO pasa por un divisor; la señal del servo lleva una resistencia serie (limita la
corriente si el servo inyecta ruido) y un pull-down (evita movimientos al arrancar, cuando el GPIO está en alta
impedancia); la ESP32-CAM no se cablea al ESP32 (solo Wi-Fi).

## 15. Tabla de conexiones pin por pin

| Componente | Pin | Conectar a | Función | Observación |
|---|---|---|---|---|
| HC-SR04 | VCC | Bus 5,0 V (Buck B) | Alimentación | 15 mA (hoja de datos). La versión clásica necesita 5 V |
| HC-SR04 | GND | GND común | Tierra | — |
| HC-SR04 | TRIG | ESP32 **GPIO26** | Disparo (pulso 10 µs) | 3,3 V supera el umbral TTL (V_IH 2,0 V); no requiere adaptación |
| HC-SR04 | ECHO | R1 1 kΩ → nodo → ESP32 **GPIO34**; nodo → R2 2 kΩ → GND | Retorno (ancho = distancia) | 5 V × 2/(1+2) = **3,33 V** ≤ 3,6 V (máx. ESP32). GPIO34 es solo entrada: no puede dañarse configurándolo como salida |
| HC-SR04 n.º 2 (tolva) | VCC / GND | Bus 5,0 V / GND (por J5) | Alimentación | Cable de 4 hilos ~120 cm por la tapa y el conducto de la esquina |
| HC-SR04 n.º 2 (tolva) | TRIG | ESP32 **GPIO19** (J5) | Disparo | Sin función de arranque |
| HC-SR04 n.º 2 (tolva) | ECHO | R5 1 kΩ → nodo → ESP32 **GPIO21**; nodo → R6 2 kΩ → GND | Nivel de alimento | Mismo divisor que el de presencia: 3,33 V |
| MG995 | SIGNAL (naranja) | 330 Ω → ESP32 **GPIO25**; 10 kΩ de GPIO25 a GND | PWM 50 Hz, 0,5–2,5 ms | GPIO25 no es de arranque (strapping) ni emite pulsos al iniciar |
| MG995 | VCC (rojo) | Salida **Buck A 6,0 V** | Alimentación | Fuente ≥ 3 A; C1 1000–2200 µF junto al conector |
| MG995 | GND (marrón) | GND común (en el conector del servo) | Tierra | Necesario para que la señal tenga referencia |
| ESP32 | VIN | Bus 5,0 V | Alimentación | Regulador interno (AMS1117 en la mayoría de placas) a 3,3 V |
| ESP32 | GND | GND común | Tierra | — |
| ESP32 | 3V3 | **Sin conexión externa** | — | No alimenta servo ni sensores |
| ESP32 | **GPIO35** | Divisor 100 kΩ/33 kΩ de VBAT | Medición batería | ADC1. 8,4 V → 2,08 V |
| ESP32 | **GPIO32** | Divisor 100 kΩ/33 kΩ del riel 6 V | Medición servo | ADC1. 6,0 V → 1,49 V |
| ESP32 | **GPIO33** | Divisor 100 kΩ/100 kΩ del panel | Medición panel | ADC1. Tensión del panel / 2 |
| ESP32 | GPIO2 | LED de la placa | Indicador | Pin de arranque; ya tiene el LED con su resistencia |
| ESP32 | GPIO0 | Botón BOOT de la placa | Borrar errores (2 s) | Se lee solo después del arranque |
| ESP32-CAM | 5V | Bus 5,0 V | Alimentación | 470 µF + 100 nF junto al módulo |
| ESP32-CAM | GND | GND común | Tierra | — |
| ESP32-CAM | U0R, U0T, IO0 | Solo al programar (USB-TTL) | Carga del firmware | Desconectados en funcionamiento |
| Panel (estación remota) | + | Cable 3–5 m → GX12 pin 1 → D1 1N5817 → entrada del elevador MT3608; antes de D1, divisor 100k/100k → GPIO33 | Captación | Medir V<sub>oc</sub> e I<sub>sc</sub> reales |
| Panel (estación remota) | − | Cable → GX12 pin 2 → GND común | — | — |
| MT3608 | OUT+ (5,0 V) | Entrada 5 V del cargador 2S | Carga solar | Ajustar a 5,0 V **sin carga** |
| Cargador 2S | OUT+ / OUT− | BMS P+ / P− | Carga CC/CV 8,4 V | BMS de puerto común |
| BMS 2S | B+, BM, B− | Celda 2 (+), punto medio, celda 1 (−) | Protección y balanceo | — |
| BMS 2S | P+ | F1 4 A → S1 → bus VBAT | Salida de batería | — |
| BMS 2S | P− | GND común (punto estrella) | — | — |
| Buck A / Buck B | IN+ / IN− | Bus VBAT / GND | Entrada 6,0–8,4 V | Ajustar salidas **antes** de conectar cargas |

### Auditoría de los GPIO elegidos (ESP32-WROOM-32)

| GPIO | Uso | Por qué es seguro |
|---|---|---|
| 26 | TRIG | Salida digital común; no es de arranque; es ADC2 pero no se usa como analógico |
| 34 | ECHO | Solo entrada, sin pull internos (el divisor fija el nivel), ADC1 |
| 25 | PWM servo | No es de arranque; LEDC disponible; sin actividad durante el arranque |
| 19 / 21 | TRIG2 / ECHO2 (nivel de la tolva) | GPIO de uso general, sin función de arranque ni de flash; ECHO2 llega por el divisor R5/R6. Están en la otra fila del DevKit, junto a J5 |
| 35, 32, 33 | ADC | **ADC1**: funciona con el Wi-Fi activo (ADC2 no) |
| 2, 0 | LED / botón | Pines de arranque ya cableados en la placa; solo se usan después de arrancar |
| **Evitados** | 6–11 (memoria flash), 1 y 3 (UART del USB), 12 (selecciona la tensión de la flash: un nivel alto al arrancar impide iniciar), 15 y 5 (arranque), 14 (emite PWM al arrancar), ADC2 para medidas analógicas | — |

Sin conflictos: cada GPIO tiene una sola función y ninguno comparte periférico.

**Arnés de cables** (qué cable va de qué módulo a cuál, conductores, sección y longitud aproximada medida sobre el
modelo 3D): ver [`Documentation/wiring/placa_control.md`](Documentation/wiring/placa_control.md#arnés-de-cables-de-la-torre).

## 16. Alimentación eléctrica

### A. ESP32
Bus 5,0 V → VIN → regulador de la placa → 3,3 V. Consumo estimado de la **placa** con Wi-Fi conectado: ≈ 80–150 mA
a 5 V (el chip consume ≈ 95–100 mA recibiendo y hasta ≈ 240 mA en ráfagas de transmisión, según Espressif; la placa
añade el puente USB y el LED). **Medir.** Pico de diseño 0,25 A.

### B. ESP32-CAM
Bus 5,0 V → pin 5V. Especificación AI-Thinker: **180 mA a 5 V** sin flash, **310 mA** con flash. Muy sensible a caídas
(reinicios por *brownout*): 470 µF + 100 nF junto al módulo y cable corto.

### C. HC-SR04 (×2)
Bus 5,0 V. 15 mA midiendo y < 2 mA en reposo (hoja de datos). El de presencia se calcula midiendo siempre (peor caso);
el de la tolva mide una vez por minuto, así que pesa sus 2 mA de reposo.

### D. MG995
**Buck A 6,0 V exclusivo**, ≥ 3 A. En movimiento 0,5–0,9 A y bloqueado ≈ 2,5 A (valores de hojas de datos de
distribuidores a 6 V; medir). El firmware **libera** el servo (sin pulsos) al terminar cada dosis para que no consuma
corriente de retención ni se caliente si quedó trabado.

### E. Sistema solar
Estación remota: panel → cable 3–5 m → GX12 en el cajón → D1 → MT3608 (5 V) → cargador 2S → BMS → batería. Con
100 mA, 5 m de cable AWG 22 (ida y vuelta) restan ≈ 0,05 V: despreciable. Análisis completo en §21.

### Consumo, picos y autonomía (calculado con [`Documentation/power/calculo_energia.py`](Documentation/power/calculo_energia.py))

| Concepto | Valor | Base |
|---|---|---|
| ESP32 DevKit | 0,50 W | 0,10 A × 5 V (estimado) |
| ESP32-CAM | 0,90 W | 0,18 A × 5 V (AI-Thinker) |
| HC-SR04 presencia | 0,075 W | 15 mA × 5 V (peor caso) |
| HC-SR04 nivel de tolva | 0,010 W | 2 mA × 5 V (reposo; mide 1 vez/min) |
| Lógica total con pérdidas DC-DC (85 %) | 41,9 Wh/día | Wi-Fi siempre conectado |
| MG995 (6 raciones × 3 ciclos/día) | 0,10 Wh/día | 0,7 A × 6 V × 4 s por ciclo |
| **Total** | **42,0 Wh/día (1,75 W medios)** | — |
| Pico riel 5 V | 0,59 A | ESP32 TX + cámara con flash + 2 sensores → Buck B ≥ 2 A |
| Pico riel 6 V | 2,5 A | servo bloqueado → Buck A ≥ 3 A |
| Pico en batería | 3,3 A a 6,4 V | → BMS ≥ 5 A, fusible 4 A **lento** (tolera picos breves) |
| Batería 2S1P 2500 mAh | 18,5 Wh nominal / 14,8 Wh útiles | 80 % utilizable |
| **Autonomía 2S1P** | **≈ 8,5 h** | Suficiente para una jornada de feria si se carga antes |
| Autonomía 2S2P | ≈ 17 h | Recomendado |

Las pérdidas dominantes son el consumo continuo del Wi-Fi de dos módulos y la conversión DC-DC; el servo es
despreciable en energía pero **dominante en picos**.

## 17. Análisis del MG995

| Parámetro | Valor | Fuente / comentario |
|---|---|---|
| Tensión de funcionamiento | 4,8–7,2 V | Hoja de datos Tower Pro |
| Par de bloqueo | 8,5 kgf·cm (4,8 V) / 10 kgf·cm (6 V) | Tower Pro |
| Velocidad | 0,20 s/60° (4,8 V) / 0,16 s/60° (6 V) | Tower Pro |
| Corriente en movimiento | 0,5–0,9 A (6 V) | Distribuidores; **medir** |
| Corriente de bloqueo | ≈ 2,5 A (6 V) | Distribuidores; **medir** |
| Señal | PWM 50 Hz (20 ms); 1–2 ms nominal; muchas unidades aceptan 0,5–2,5 ms | El ángulo exacto por µs varía: **calibrar** |
| Banda muerta | 5 µs | Tower Pro |
| Dimensiones | 40,7 × 19,7 × 42,9 mm, 55 g | Tower Pro |
| Versiones | Existe un "MG995 360°" de **giro continuo** | Este diseño requiere la versión **180° posicional**. Comprobar: con `SERVO 1000` y `SERVO 2000` debe ir a dos posiciones y quedarse quieto |

**Conexión:** ESP32 → solo señal (GPIO25 con 330 Ω). Fuente Buck A 6,0 V → V+. GND del Buck A → GND común con el ESP32.
**Nunca** desde un GPIO (máx. ≈ 40 mA), ni desde 3V3, ni desde VIN del ESP32, ni directo de la batería 2S (8,4 V > 7,2 V).

**Nivel lógico:** el umbral de entrada del MG995 no está publicado; en la práctica responde a 3,3 V. Si en la Prueba 3
vibra o no responde con la alimentación correcta, añadir un buffer **74AHCT125** alimentado a 5 V (convierte 3,3 V → 5 V).

**Capacidad mecánica:** con 10 kgf·cm a 6 V, en el borde del bolsillo (r ≈ 54 mm) la fuerza disponible es ≈ 18 N. Mover
el disco solo vence el rozamiento; el riesgo real es **una croqueta pellizcada** entre el bolsillo y el borde de la
entrada (romperla puede requerir más fuerza de la disponible). Por eso el diseño incluye chaflanes anti-cizalla, rampa
lenta, agitación y retroceso automático (§22), y el firmware libera el servo si detecta un bloqueo.

**Limitación:** el MG995 **no informa su posición** ni su corriente. La detección de atasco del firmware es **indirecta**
(caída sostenida de la tensión del riel de 6 V medida en GPIO32). Una detección fiable exigiría un sensor de corriente
(p. ej. INA219), que queda como mejora futura porque no está en la lista de componentes principales.

## 18. Análisis del HC-SR04

| Parámetro | Valor (hoja de datos) | Consecuencia |
|---|---|---|
| VCC | 5 V | Del bus de 5 V |
| Corriente | 15 mA | Despreciable |
| TRIG | Pulso TTL ≥ 10 µs | 3,3 V del ESP32 es alto válido |
| ECHO | Pulso de **5 V**, ancho proporcional a la distancia (cm = µs / 58) | **Divisor obligatorio** |
| Rango | 2 cm – 4 m, ángulo ≈ 15° | Umbral de detección 35 cm (PROVISIONAL) |
| Ciclo de medida | ≥ 60 ms | El firmware lo respeta |

**Adaptación de nivel:** R1 = 1 kΩ en serie desde ECHO; R2 = 2 kΩ del GPIO a GND → V = 5 × 2/3 = 3,33 V
(con 5,1 V: 3,40 V), por debajo del máximo de 3,6 V y por encima del umbral alto del ESP32 (0,75 × 3,3 = 2,48 V).
La impedancia (≈ 667 Ω) es baja: no deforma el pulso.

**Si su módulo es HC-SR04P / RCWL-9610** (versiones de 3–5,5 V): puede alimentarse a 3,3 V y conectarse sin divisor.
Identificar el modelo antes de cablear; ante la duda, alimentar a 5 V con divisor (es seguro para ambas).

**Limitaciones reales:** el pelaje largo absorbe ultrasonido (alcance menor), superficies inclinadas desvían el eco y
el sensor no distingue una mascota de una persona o una caja: **por eso la decisión final la da la cámara**.

### 18.1 Segundo HC-SR04: nivel de alimento en la tolva (recomendación del profesor)

| Aspecto | Diseño | Por qué |
|---|---|---|
| Ubicación | Cápsula 13b colgada de la tapa 13a, transductores hacia abajo, sobre la boca del embudo | El alimento solo "ve" los transductores; la placa queda en seco; la tapa tiene **llave** (una sola posición), así la calibración no cambia al abrirla |
| Alcance mínimo | Surco **MAX** dentro del embudo a 30 mm de los transductores | El HC-SR04 no mide a menos de 2 cm (hoja de datos) |
| Cableado | J5 (GPIO19 TRIG, GPIO21 ECHO por R5/R6); cable por la ranura de la tapa y el tubo cerrado de la esquina trasera izquierda | Ningún cable pasa por el alimento; ~20 cm flojos para levantar la tapa |
| Medición | Mediana de 5 disparos, una vez por minuto y después de cada ración, solo en ESPERANDO | No interfiere con la detección ni con la dosis |
| Calibración | `NIVEL VACIO` (tolva vacía) y `NIVEL LLENO` (alimento en MAX), guardadas en la flash | El eco en un embudo depende de la geometría real |
| Porcentaje | **% de VOLUMEN**, no de altura | El embudo se estrecha: con el 20 % de la altura queda solo el 4,8 % del alimento. La tabla altura → volumen (`NivelGeometria.h`) se calcula del modelo 3D y `generar_stl.py` comprueba que coincida |
| Alertas | < 20 % del volumen (≈ 126 cm³, ≈ 15 dosis del disco): **COMIDA_BAJA**; ≤ 3 %: **COMIDA_AGOTADA** (no dispensa); > 30 %: **COMIDA_REPUESTA**. Cada cambio exige 3 lecturas seguidas (histéresis 20/30 %) | Una sola alerta por evento, sin repetirse por ruido; capacidad hasta MAX ≈ 632 cm³ |
| Entrega | `POST /alerta` al PC (panel web + ntfy al celular); si el PC no responde, reenvío cada 30 s | Que el aviso llegue aunque el PC se haya reiniciado |
| Fallo del sensor | Sin eco 3 veces → aviso único `SENSOR_NIVEL_SIN_LECTURA`; **no bloquea** la alimentación | Un sensor roto no debe dejar sin comer a la mascota |

**Limitación honesta:** el ultrasonido mide la distancia a la superficie en un cono de ≈ 15°; si las croquetas forman
un montículo o un "cráter" sobre la boca, el porcentaje varía unos puntos. Por eso las alertas tienen histéresis y
exigen 3 lecturas, y la calibración se hace con el alimento nivelado.

## 19. Análisis del ESP32

* **Alimentación:** 5 V por VIN (o USB). Lógica a 3,3 V; los GPIO **no toleran 5 V** (máx. V<sub>DD</sub> + 0,3 V).
* **GPIO en los conectores de la DevKit V1 de 30 pines:** 2, 4, 5, 12–19, 21–23, 25–27, 32–35, 36 (VP), 39 (VN) y 1/3
  (UART del USB). GPIO0 no sale al conector: solo está unido al botón BOOT (por eso se usa como botón de reset de errores).
* **Recomendados para uso general:** 4, 13, 16–19, 21–23, 25–27, 32, 33; entradas puras: 34, 35, 36, 39.
* **A evitar:** 6–11 (flash interna), 1/3 (UART del USB), 12 (selecciona la tensión de la flash), 0, 2, 5, 15 (arranque),
  14 (pulsos al arrancar). Con Wi-Fi activo **no** se puede usar ADC2 (0, 2, 4, 12–15, 25–27).
* **PWM:** periférico LEDC (16 canales, resolución configurable). A 50 Hz se usan 16 bits → paso ≈ 0,3 µs, muy inferior
  a la banda muerta del servo (5 µs).
* **GND:** todos los GND de la placa están unidos; se conecta al punto estrella.
* **Wi-Fi:** 802.11 b/g/n solo 2,4 GHz; picos de ≈ 240 mA al transmitir → alimentación con margen y condensadores.
* **Conflictos detectados:** ninguno con la asignación elegida (§15). El sensor de nivel usa GPIO19 y GPIO21 (uso
  general, sin función de arranque).
* **Dato a verificar:** si la placa tiene diodo entre el USB y VIN. Si no lo tiene, no conectar el USB y el bus de 5 V a la vez.
* **Memoria:** el firmware ocupa el 72 % (núcleo 2.0.17) o el 83 % (núcleo 3.0.7) de la partición de programa por
  defecto (1,25 MB) y ≈ 48 kB de RAM estática. Si se añaden funciones con el núcleo 3.x, elegir el esquema de
  particiones *Huge APP*.

## 20. Análisis de la ESP32-CAM

* **Alimentación:** 5 V por el pin 5V (regulador interno a 3,3 V). Consumo AI-Thinker: 180 mA sin flash, 310 mA con flash.
* **Programación:** sin USB; adaptador USB-TTL 3,3 V (TX→U0R, RX→U0T) o placa ESP32-CAM-MB; GPIO0 a GND para entrar en
  modo de carga.
* **GPIO ocupados por la cámara:** 0 (XCLK), 5, 18, 19, 21, 22, 23, 25, 26 (SDA), 27 (SCL), 32 (PWDN), 34, 35, 36, 39;
  16 = PSRAM; 4 = flash; 33 = LED rojo; 1/3 = UART. Los únicos "libres" (2, 12, 13, 14, 15) son de la tarjeta SD y varios
  son de arranque → **no se usa ninguno**: la comunicación es por Wi-Fi.
* **Wi-Fi:** antena impresa; dentro de la cápsula de plástico funciona (no usar carcasas metálicas).
* **Limitaciones:** calidad de imagen modesta (sensor OV2640 de 2 MP), poca luz → imágenes oscuras (se detecta y se
  devuelve clase 0), calentamiento (≈ 0,9 W): la cápsula tiene ventilación; brownouts con fuentes débiles.

## 21. Análisis del sistema solar

**Datos del panel:** ≈ 3 V × 100 mA → **P = 0,3 W** en condiciones estándar (1000 W/m², 25 °C). La etiqueta "1 W" de
algunos anuncios es incompatible con 3 V × 0,1 A, así que **se usa 0,3 W** y se recomienda medir V<sub>oc</sub>
(circuito abierto) e I<sub>sc</sub> (cortocircuito con el amperímetro) al sol.

**¿Puede alimentar algo por sí solo?**

| Carga | Necesita | Panel (0,3 W pico) | Conclusión |
|---|---|---|---|
| ESP32 con Wi-Fi | ≈ 0,5 W continuos, picos > 1 W | 0,3 W solo a pleno sol | **No** |
| ESP32-CAM | ≈ 0,9 W continuos, picos 1,5 W | — | **No** |
| HC-SR04 | 0,075 W | En potencia sí, pero necesita 5 V estables y el panel da ≈ 3 V variables | No directamente |
| MG995 | 3–5 W en movimiento, 15 W bloqueado | — | **No, en ningún caso** |
| Sistema completo | 1,75 W medios = 42,0 Wh/día | 0,72 Wh/día (4 h de sol pico, 60 % de rendimiento) | **Aporta ≈ 1,7 %** |
| Sistema en la feria (luz artificial) | — | ≈ 0,01 Wh/día | **≈ 0,03 %**: prácticamente cero |

**Estación solar remota (recomendación del profesor):** el panel ya no va sobre la torre: se monta en la estación
12a + 12b, que se coloca donde haya sol directo (un balcón, una ventana, el patio), hasta a 3–5 m del dispensador, y
se conecta al cajón de energía con un cable bipolar de exterior y un conector **GX12** de 2 pines (polarizado, con
rosca). Ventajas: la torre puede estar en la sombra o en el interior (donde está la mascota) y el panel recibe el sol
que le corresponde; la bandeja se orienta de 0° a 75° (inclinación ≈ latitud del lugar, mínimo 10–15° para que
escurra el agua, mirando al ecuador) y se fija con dos tornillos M4. La medición `v_panel` se hace en el cajón: la
caída en el cable es ≈ 0,05 V (despreciable). La estación se imprime en PETG o ASA (sol y lluvia).

**Arquitectura energética físicamente válida:**

```
PANEL ≈3 V (estación remota) ─▶ cable 3–5 m ─▶ GX12 ─▶ D1 Schottky ─▶ ELEVADOR MT3608 (5,0 V) ─▶ CARGADOR 2S (CC/CV 8,4 V) ◀─ USB-C 5 V
                                                              │
                                                    BMS 2S + 2×18650 (ALMACENAMIENTO)
                                                              │
                                              F1 4 A ─▶ S1 ─▶ bus 6,0–8,4 V
                                                              ├─▶ BUCK A 6,0 V ─▶ MG995       (REGULACIÓN)
                                                              └─▶ BUCK B 5,0 V ─▶ lógica
```

* **Por qué el elevador:** el panel da ≈ 3 V y cualquier cargador de litio necesita más tensión que la batería.
  Sin seguimiento del punto de máxima potencia (MPPT), con poca luz el elevador puede entrar y salir de servicio:
  el rendimiento real **se mide** (Prueba E). Que el cargador acepte una fuente tan débil depende del modelo exacto:
  **verificar**.
* **Papel honesto del panel en el proyecto:** demostrar la cadena de captación → carga → almacenamiento → regulación y
  **medirla** (`v_panel` en `/status`), no alimentar el dispensador.
* **Para autonomía solar real** (mejora): panel de **≈ 14 W** con controlador MPPT compatible con 2S (8,4 V) y batería de
  ≈ 84 Wh (2 días), o reducir el consumo apagando la ESP32-CAM entre detecciones (requiere un MOSFET y ≈ 3 s de arranque).
  La estación remota ya deja el panel donde hay sol: un panel más grande solo necesitaría otra bandeja (cambiando
  `PANEL_W`/`PANEL_H` en `generar_stl.py`).
* **Seguridad:** celdas de marca con capacidad real (desconfiar de "9800 mAh"), BMS siempre, fusible, nada de soldar
  directamente sobre las celdas sin experiencia (usar portapilas), cargar bajo supervisión.

## 22. Dosificación

### 22.1 Evaluación de mecanismos

| Mecanismo | Compatible con MG995 de 180° | Repetibilidad | Atascos con croquetas | Decisión |
|---|---|---|---|---|
| Sinfín | **No** (necesita giro continuo y par sostenido) | Media (depende del tiempo) | Alto | Descartado |
| Compuerta | Sí | **Baja** (caudal depende del nivel de la tolva y de las bóvedas) | Medio | Descartado |
| Rueda de celdas | Solo con giro continuo (servo 360°) | Media (tiempo de giro) | Medio | Descartado |
| **Disco volumétrico con un bolsillo y vaivén** | **Sí** (100° de recorrido) | **Alta** (volumen fijo por ciclo) | Bajo-medio con chaflanes y retroceso | **Elegido** |

### 22.2 Funcionamiento

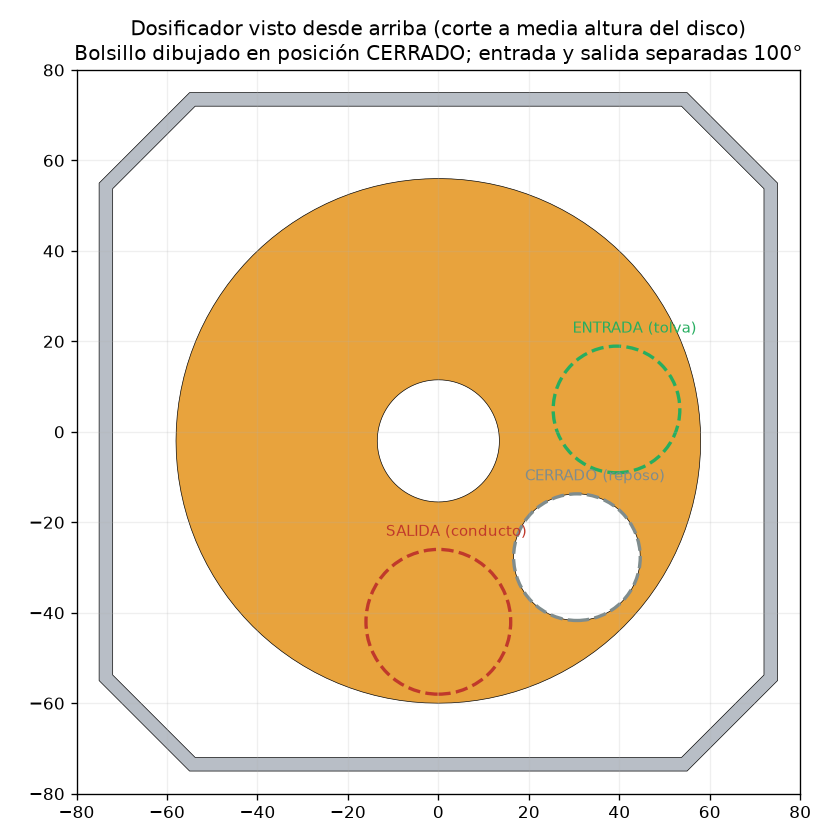
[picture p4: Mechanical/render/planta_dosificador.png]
Planta del dosificador


1. **Entra:** la tolva cónica (paredes ≥ 55°) termina en una boca Ø28 sobre la **entrada** de la placa superior (08c).
2. **Llenado:** el servo lleva el bolsillo (Ø28 × 14 mm = **8,6 cm³ geométricos**) bajo la entrada; el alimento cae por
   gravedad; dos pequeñas oscilaciones (±40 µs) lo asientan.
3. **Traslado:** el disco gira 100°; durante el giro el bolsillo está tapado arriba y abajo. La geometría está verificada:
   el bolsillo **nunca** se superpone a la entrada y a la salida a la vez (margen 15°), así que nunca hay paso directo
   tolva → conducto.
4. **Sale:** sobre la **salida** Ø32 (mayor que el bolsillo para que nada se enganche) el alimento cae al conducto.
5. **Reposo:** el disco vuelve a **CERRADO** (a mitad de camino, sin conexión con ninguna abertura) y el servo se libera.
6. **Regulación:** ración = **N ciclos** (`CICLOS_PERRO`, `CICLOS_GATO`). Los gramos por ciclo se miden (§23).

### 22.3 Prevención de atascos y mantenimiento

* Chaflán de 1,2 mm en el borde inferior de la entrada y de 1,5 mm en la boca del bolsillo (reducen el pellizco).
* Rampa lenta (≈ 1 s por 1000 µs), agitación, holgura de 0,5 mm bajo el disco y 1 mm en el borde.
* Si el riel de 6 V cae de forma sostenida (bloqueo), el disco **retrocede** a la posición anterior y reintenta (2 veces);
  si persiste: `ERROR_MECANISMO`, servo liberado, requiere intervención.
* Grano recomendado ≤ 14 mm (mitad del bolsillo). Para croquetas grandes: aumentar `D_BOLSILLO` y `D_ENTRADA` en
  `generar_stl.py` (la verificación angular avisa si deja de ser seguro).
* Limpieza: se retira la tapa (con el sensor de nivel, sin desconectarlo), se levanta la tolva, se quita la placa
  superior a mano (asiento cónico + chaveta, sin tornillos) y el disco se desatornilla del horn.

## 23. Calibración

Todos los valores finales se obtienen **experimentalmente**. Plantillas en [`Documentation/calibration`](Documentation/calibration).

### 23.1 Posiciones del servo (sin alimento, sin placa superior)
1. Con `SERVO 1500` montar el horn y el disco con su marca en la marca **CERRADO** de 08d.
2. Con `SERVO <us>` (pasos de 20 µs) buscar el pulso que alinea el bolsillo con la marca **ENTRADA** → `PULSO_LLENADO_US`.
3. Igual con la marca **SALIDA** → `PULSO_DESCARGA_US`. Comprobar a ojo que el bolsillo cubra completamente cada agujero.
4. Si las posiciones requieren < 500 µs o > 2500 µs, el servo no tiene recorrido suficiente: revisar que sea la versión de 180°.

### 23.2 Cantidad de alimento
```
Movimiento del MG995 → ciclo llenar/descargar → alimento entregado → balanza (resolución ≤ 1 g)
→ planilla CSV → analizar_dosificacion.py → CICLOS por ración → config.h
```
1. Tolva llena con **el alimento real** (la densidad cambia entre marcas). Comando `CICLO 1`, pesar, anotar. Repetir
   **10 veces** con la tolva llena, media y baja (`plantilla_dosificacion.csv`).
2. `python analizar_dosificacion.py plantilla_dosificacion.csv --objetivo-g 30` → gramos/ciclo (media), desviación,
   **coeficiente de variación** (repetibilidad) y ciclos necesarios para la ración con su margen de error.
3. Criterio: CV ≤ 10 %. Si es mayor, aumentar `T_LLENADO_MS` o `AGITACIONES` y repetir.
4. Copiar `CICLOS_PERRO` / `CICLOS_GATO` a `config.h` (respetando `MAX_CICLOS_POR_RACION`). La ración diaria la define
   el veterinario o la etiqueta del alimento, no el sistema.

### 23.3 Tiempo
`T_LLENADO_MS` y `T_DESCARGA_MS`: empezar en 700/600 ms y bajar de 100 en 100 ms mientras los gramos por ciclo no
disminuyan (el tiempo mínimo que llena el bolsillo).

### 23.4 Distancia de detección
`DIST` en el monitor serie con una caja y con un peluche (simula pelaje) a 10/20/30/40 cm, 5 lecturas cada una
(`plantilla_distancia.csv`). Fijar `DIST_DETECCION_CM` entre el borde del comedero y el punto donde la mascota se para,
y `DIST_LIBRE_CM` ≈ 15 cm más.

### 23.5 Cámara y clasificación
`capturar_dataset.py` con 30 fotos de perro, 30 de gato y 30 de "otros" (personas, fondo, juguetes) **con la torre en
su lugar y su iluminación** → `probar_imagenes.py dataset --barrido` → elegir el umbral sin decisiones peligrosas
(perro↔gato o dispensar a "otros"). Ajustar `BRILLO_*` y `NITIDEZ_MIN` con los valores impresos para las fotos buenas y malas.

### 23.6 Sensor de nivel de la tolva
Con la tapa puesta: tolva vacía → `NIVEL VACIO`; alimento nivelado en el surco MAX → `NIVEL LLENO`; `NIVEL` debe
indicar ≈ 100 %. Para saber cuántos gramos son el 20 % de aviso, pesar una taza del alimento (densidad aparente) y
multiplicar por ≈ 126 cm³. Detalle en el [manual de armado](Documentation/manual_armado/Manual_de_Armado.md#3-calibración-del-sensor-de-nivel).

### 23.7 Tiempo entre dispensaciones
`COOLDOWN_*` y `MAX_RACIONES_DIA_*` son **política de uso**: `MODO_FERIA 1` (30 s / 60 s) para demostrar,
`MODO_FERIA 0` con los valores que defina el dueño.

## 24. Máquina de estados

```mermaid
stateDiagram-v2
  [*] --> ESPERANDO: Wi-Fi conectado
  [*] --> ERROR_WIFI: sin Wi-Fi
  ESPERANDO --> DETECTADO: 3 lecturas entre 3 y 35 cm, zona rearmada, sin cooldown
  DETECTADO --> CAPTURANDO
  CAPTURANDO --> PROCESANDO: camara responde
  CAPTURANDO --> ERROR_CAMARA: 2 fallos
  PROCESANDO --> CLASIFICADO: HTTP 200 con clase 0, 1 o 2
  PROCESANDO --> ERROR_CAMARA: HTTP 502
  PROCESANDO --> ERROR_CLASIFICACION: timeout o JSON invalido
  CLASIFICADO --> CAPTURANDO: clase 0, sigue presente, menos de 5 fotos, otra foto tras 2 s
  CLASIFICADO --> ESPERANDO: no permitido o se fue
  CLASIFICADO --> DOSIFICANDO: clase 1 o 2 permitida
  CLASIFICADO --> ERROR_SERVO: riel 6 V ausente
  DOSIFICANDO --> FINALIZADO: dosis completa
  DOSIFICANDO --> ERROR_MECANISMO: atasco
  DOSIFICANDO --> ERROR_SERVO: riel perdido
  FINALIZADO --> ESPERANDO: bloqueo temporal
  ERROR_WIFI --> ESPERANDO: reconectado
  ERROR_CAMARA --> ESPERANDO: camara recuperada
  ERROR_CLASIFICACION --> ESPERANDO: PC recuperado
  ERROR_ALIMENTACION --> ESPERANDO: VBAT mayor o igual a 7,0 V
  ERROR_SERVO --> ESPERANDO: BOOT 2 s o RESET
  ERROR_MECANISMO --> ESPERANDO: BOOT 2 s o RESET
```

| Estado | Entrada | Acción | Salida |
|---|---|---|---|
| ESPERANDO | Inicio con Wi-Fi, fin de ciclo o error recuperado | Mide distancia cada 50 ms; rearma si la zona está libre ≥ 3 s (> 50 cm) | DETECTADO tras 3 lecturas en [3, 35] cm, zona armada y cooldown global cumplido |
| DETECTADO | Presencia confirmada | Reinicia contadores de intentos | CAPTURANDO (inmediato) |
| CAPTURANDO | Detección o foto siguiente | `GET cámara/status` solo antes de la primera foto (en las siguientes, si la cámara falla el PC responde 502) | PROCESANDO si responde; ERROR_CAMARA tras 2 fallos |
| PROCESANDO | Cámara lista | `GET PC/classify` (10 s) | CLASIFICADO (200), ERROR_CAMARA (502), ERROR_CLASIFICACION (otro) |
| CLASIFICADO | Respuesta válida | Clase 0: si sigue presente, otra foto a los 2 s (máx. 5 por visita). Clase 1/2: verifica habilitación, cooldown de clase, límite 24 h, presencia, riel 6 V | DOSIFICANDO, CAPTURANDO, ESPERANDO o ERROR_SERVO |
| DOSIFICANDO | Ración autorizada | N ciclos con vigilancia del riel | FINALIZADO, ERROR_MECANISMO o ERROR_SERVO |
| FINALIZADO | Dosis completa | Registra la ración (hora, clase, totales) | ESPERANDO con detección **desarmada** |
| ERROR_WIFI | Wi-Fi perdido | Reintenta cada 5 s; reinicia a los 5 min | ESPERANDO al reconectar |
| ERROR_CAMARA | Cámara sin respuesta | Reintenta cada 30 s | ESPERANDO si responde |
| ERROR_CLASIFICACION | PC sin respuesta o respuesta inválida | Reintenta `/status` del PC cada 30 s | ESPERANDO si responde |
| ERROR_ALIMENTACION | VBAT < 6,8 V | No dispensa | ESPERANDO con VBAT ≥ 7,0 V (histéresis) |
| ERROR_SERVO | Riel de 6 V ausente/bajo | Bloqueante (no se reintenta solo) | Botón BOOT 2 s o comando `RESET` |
| ERROR_MECANISMO | Atasco tras 2 retrocesos | Servo liberado; bloqueante | Botón BOOT 2 s o comando `RESET` |

**Vigilancia del nivel de la tolva** (no es un estado aparte: corre dentro de ESPERANDO, cada 60 s y después de cada
ración, para no interferir con una detección o una dosis): 3 lecturas seguidas < 20 % → alerta `COMIDA_BAJA`;
≤ 3 % → `COMIDA_AGOTADA` y la regla de ración rechaza dispensar; > 3 % después de agotada → vuelve a `COMIDA_BAJA`
(recarga parcial); > 30 % → `COMIDA_REPUESTA`. Sin eco → aviso `SENSOR_NIVEL_SIN_LECTURA` una sola vez, sin bloquear.
Una alerta que el PC no confirma (HTTP 200) se reenvía cada 30 s.

## 25. Manejo de errores

| Error | Detección | Reacción | Recuperación |
|---|---|---|---|
| Mascota lejos / sensor tapado | Distancia > 35 cm o < 3 cm | No se activa nada | Automática |
| Mascota se va | Distancia antes de reintentar y antes de dispensar | No dispensa, desarma | Al volver tras zona libre |
| Imagen inválida/oscura/sobreexpuesta/borrosa | OpenCV en el PC | Clase 0 con motivo | Foto nueva a los 2 s si sigue presente (máx. 5) |
| Clasificación incierta o ambigua | Umbral, margen y fotos de la visita | Clase 0 → **no dispensar** | Foto nueva a los 2 s si sigue presente (máx. 5) |
| Perro y gato en la misma visita | Las fotos de la visita se promedian | `AMBIGUO` → **no dispensar** | Cuando se vaya uno (las fotos de más de 5 s se olvidan) |
| Wi-Fi desconectado | `WiFi.status()` cada ciclo | ERROR_WIFI, LED parpadea | Reconexión / reinicio |
| ESP32-CAM no responde | `/status` falla o PC devuelve 502 | ERROR_CAMARA | Reintento 30 s |
| PC no responde | Timeout, conexión rechazada o JSON inválido | ERROR_CLASIFICACION | Reintento 30 s |
| Servo sin alimentación | Riel < 4,6 V antes o < 1 V durante | ERROR_SERVO (bloqueante) | Revisar Buck A / cables + BOOT (una pulsación larga = un solo borrado; hay que soltar para el siguiente) |
| Atasco | Riel < 4,2 V durante ≥ 250 ms | Retroceso ×2, luego ERROR_MECANISMO, servo liberado | Limpiar disco + BOOT |
| Batería insuficiente | VBAT < 6,8 V | ERROR_ALIMENTACION (no dispensa) | Cargar (histéresis 0,2 V) |
| Panel insuficiente | `v_panel` en `/status` | No bloquea (la batería alimenta) | — |
| Repetición excesiva | Cooldown global, por clase, límite 24 h, rearmado | No dispensa | Automática |
| Desborde de `millis()` (49,7 días) | Restas sin signo | Sin efecto | Probado |
| Comida por acabarse | Nivel < 20 % del volumen, 3 lecturas | Alerta `COMIDA_BAJA` (panel web y celular), sigue dispensando | Recargar: `COMIDA_REPUESTA` al superar 30 % |
| Tolva vacía | Nivel ≤ 3 %, 3 lecturas | Alerta `COMIDA_AGOTADA`; **no dispensa** (el disco giraría en vacío) | Recargar (aunque sea parcialmente) |
| Sensor de nivel sin eco | 3 lecturas sin eco | Aviso `SENSOR_NIVEL_SIN_LECTURA` (una vez); **no bloquea** | Revisar el cable de J5 y la tapa |
| PC no recibe la alerta | `POST /alerta` sin HTTP 200 | La alerta queda pendiente (`alerta_pendiente` en `/status`) | Reenvío cada 30 s hasta entregarla |

## 26. Seguridad

* **GND común** en un punto estrella (salidas de los convertidores y P− del BMS); un cable de GND acompaña al de señal
  del servo.
* **Alimentación independiente del MG995** (Buck A): sus picos no tiran abajo el 5 V del ESP32 → evita reinicios.
* **Adaptación de niveles:** los dos ECHO por divisor (R1/R2 y R5/R6); señal del servo con 330 Ω y pull-down de 10 kΩ.
* **Caída de tensión y ruido:** 1000–2200 µF en el servo, 470 µF + 100 nF en la ESP32-CAM y en el bus 5 V, cables de
  potencia AWG 20 cortos, convertidores lejos de la antena.
* **Reinicio del ESP32:** el servo arranca sin pulsos (pull-down) y el firmware lo lleva a CERRADO y lo libera.
* **Picos de corriente:** BMS ≥ 5 A y fusible lento de 4 A; los divisores de medición están en el cajón de energía
  (por el cable solo viaja una señal de alta impedancia, nunca los 8,4 V).
* **Separación física alimento/electrónica:** conducto cerrado, tabique, cápsulas de sensores con cables que entran
  fuera del ancho del canal, placa base del dosificador sin agujeros salvo la salida y el eje con laberinto.
* **Atascos y sobrealimentación:** retroceso, liberación del servo, `MAX_CICLOS_POR_RACION`, límites diarios; la
  clase 0 nunca dispensa; sin endpoint remoto de "dar comida".
* **Sistema solar/batería:** BMS con balanceo, fusible, interruptor general, celdas en portapilas, nunca la batería
  directa a cargas de 5–7,2 V. Estación remota: conector GX12 polarizado, cable de exterior con alivio de tensión
  (brida en la base 12a), conectar y desconectar con S1 apagado.
* **Alimento:** el sensor de nivel queda por encima de la línea MAX (verificado) y no toca el alimento; la falta de
  comida se avisa antes de que el plato quede vacío y, si la tolva se agota, el dispensador no finge entregar raciones.
* **Estabilidad mecánica:** plinto de 190 mm, energía (lo más pesado) abajo, alojamientos para lastre; con un perro
  grande se recomienda fijar la base a una tabla o a la pared.

## 27. Diseño mecánico

Modelo **paramétrico en Python** ([`Mechanical/generar_stl.py`](Mechanical/generar_stl.py), biblioteca `manifold3d`)
que genera las 22 piezas y verifica automáticamente (45 comprobaciones): interferencias entre las 19 piezas de la
torre ensambladas (171 pares) y con el MG995, geometría del dosificador, recorrido del alimento, separación
electrónica/alimento, ángulo de la tolva, **sensor de nivel** (alcance mínimo, cápsula fuera del alimento, tabla
altura → volumen igual a la del firmware), **estación solar** (bandeja libre de 0° a 75°), **volumen de la Elegoo
Neptune 4 Plus** y cara de apoyo. Resultado actual: **todo correcto**.

Principios: módulos apilados con **labio macho de 6 mm** (holgura 0,3 mm) + 3 tornillos M3 radiales; placas grandes
(piso del cuerpo, placa base del dosificador) **integradas o independientes para imprimirse planas**; tetones con
cartelas a 45°; nada que requiera soportes.

## 28. Diseño de la torre

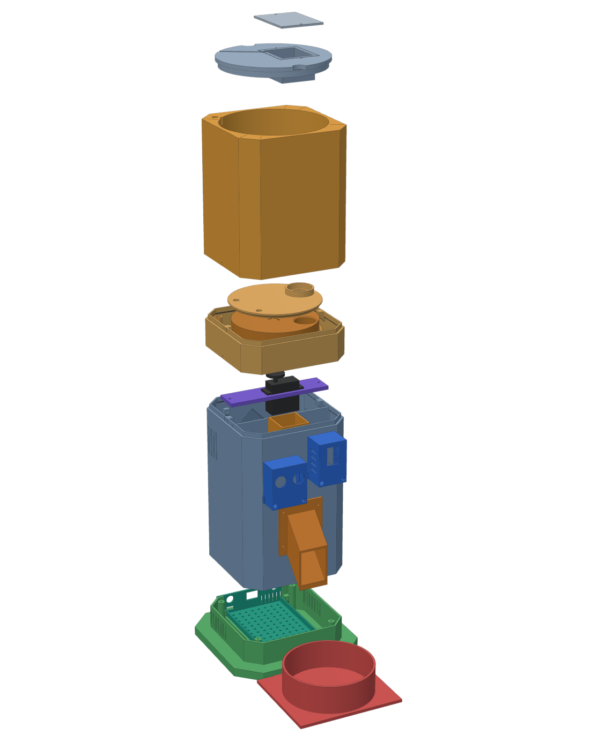
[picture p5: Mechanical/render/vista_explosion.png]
Vista explosionada


* **Sección octogonal** (150 mm con chaflanes de 20 mm), altura ≈ 49 cm → aspecto de torre tecnológica, no de caja. El
  panel ya no va en la torre: está en la **estación solar remota** (12a + 12b).
* **Capas** (de abajo arriba): Base/energía (0–45 mm) → Cuerpo: canal, sensores y electrónica (45–265) → Dosificador
  (265–303) → Tolva (303–483; ≈ 632 cm³ útiles hasta el surco MAX) → Tapa con el **sensor de nivel** (13a + 13b + 13c).
* **Modularidad y mantenimiento:** el cajón de energía sale por detrás; la bahía electrónica tiene tapa de servicio; la
  placa del ESP32 sale deslizando; las cápsulas de sensores se desatornillan desde el frente; tolva, placa superior y
  disco se retiran a mano para limpiar.
* **Cableado oculto:** pasos por el tabique, por el piso y un conducto vertical cerrado en la esquina trasera izquierda
  de la tolva y del dosificador para el cable del **sensor de nivel** (llega por una ranura sobre la tapa). El cable del
  panel entra por el conector GX12 de la tapa trasera del cajón.
* **Ventilación:** ranuras en la base (convertidores), en la bahía electrónica y en la cápsula de la cámara; ninguna en
  la zona del alimento.
* **Centro de gravedad:** batería y convertidores en la base; plinto más ancho que la torre; alojamientos de lastre.

## 29. Distribución física de los componentes

La distribución sugerida (capas de electrónica entre el dosificador y la salida) se **modificó**, porque obligaría a que
el alimento atravesara las capas de electrónica. La distribución definitiva separa en **zonas verticales**:

```
        13 TAPA + HC-SR04 n.º 2 (nivel)      cable por el conducto     ESTACIÓN SOLAR REMOTA
        ┌─────────────────────────┐          de la esquina             (12a + 12b, donde haya sol)
        │   07 TOLVA (632 cm³)    │  zona de alimento                       │ cable 3–5 m
        ├─────────────────────────┤
        │ 08 DOSIFICADOR (disco)  │  zona de alimento; MG995 debajo, en zona seca
        ├────────────┬────────────┤
        │ FRENTE     │  ATRÁS     │
        │ 09 CANAL   │ MG995 +    │  tabique entre ambas zonas
        │ (cerrado)  │ viga 06    │
        │ 03 HC-SR04 │            │  cápsulas fuera de la pared, cables
        │ 04 CAM     │ 05 ESP32   │  entran fuera del ancho del canal
        │ 10 PICO ─┐ │ (bandeja)  │
        ├──────────┼─┴────────────┤
        │ 01 BASE: │ batería, BMS,│  zona de energía (lo más pesado abajo)
        │ cajón 16 │ convertidores│ ◀── GX12 (tapa trasera) ◀────────────────┘
        └──────────┼──────────────┘
                   ▼
              11 COMEDERO
```

* **HC-SR04** a ≈ 20 cm de altura y la **ESP32-CAM** a ≈ 23 cm (inclinada 12°): ven a la mascota frente al comedero.
* **ESP32** en la bahía trasera, cerca del suelo del cuerpo (lejos de los picos del servo y del calor de los convertidores).
* **MG995** colgado bajo el disco, del lado seco del tabique.
* **HC-SR04 n.º 2** en la tapa, mirando hacia la boca del embudo, 30 mm por encima de la línea MAX.
* **Panel solar** fuera de la torre, en su estación, donde haya sol.

## 30. Recorrido del alimento

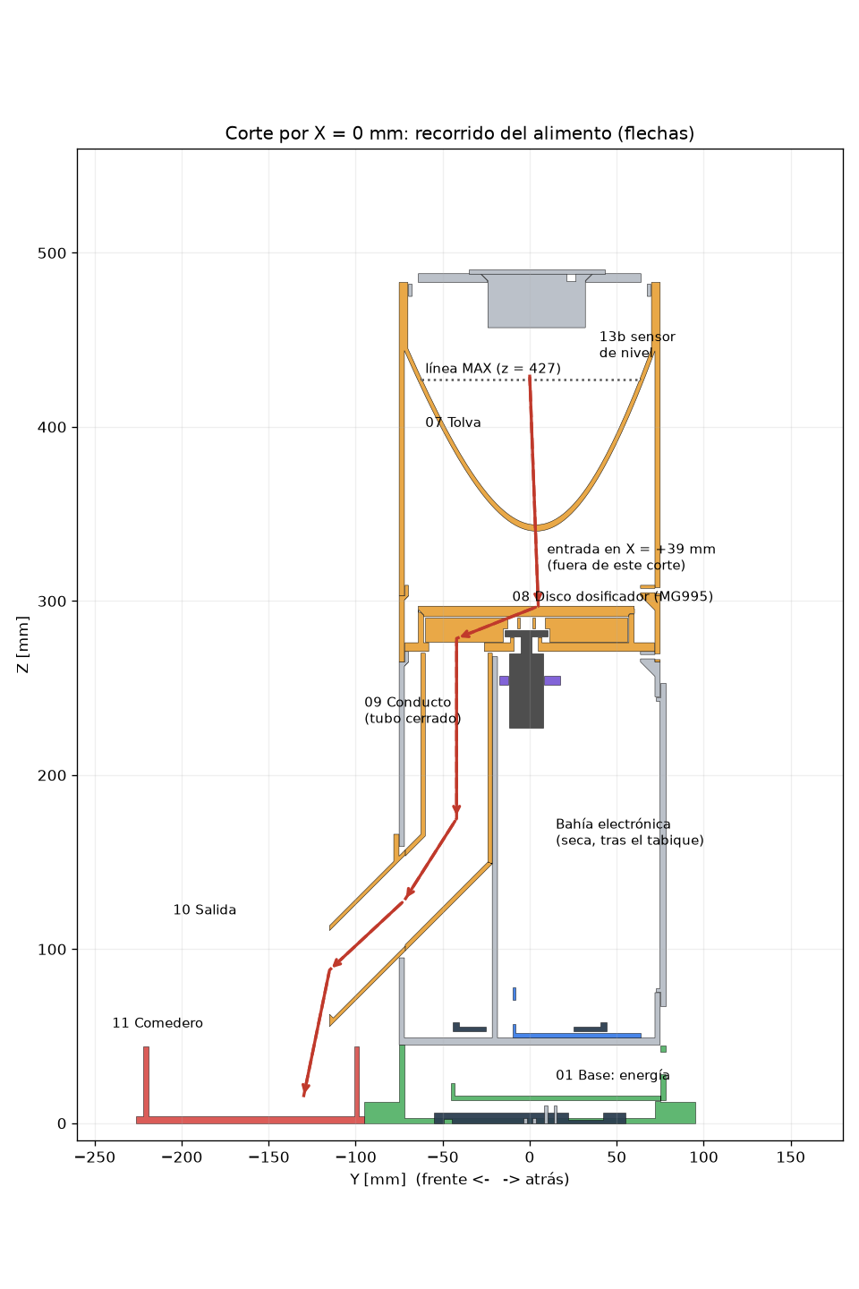
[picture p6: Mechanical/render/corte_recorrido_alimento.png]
Corte por el recorrido del alimento


```
TOLVA 07 ─▶ entrada Ø28 (08c) ─▶ bolsillo del disco 08b ─▶ salida Ø32 (08d) ─▶ CONDUCTO 09 (36×36, cerrado)
          ─▶ codo a 45° ─▶ PICO 10 ─▶ COMEDERO 11
```

* Camino **continuo**: cada tramo es igual o más ancho que el anterior (28 → 32 → 36 → 37 mm) para que nada se trabe.
* Inclinaciones ≥ 45° en todo el recorrido; tolva ≥ 55°.
* **Ninguna** pieza del recorrido contiene o toca electrónica (verificado por intersección de volúmenes con el ESP32,
  la ESP32-CAM, el HC-SR04, el MG995 y su soporte).
* El eje del servo atraviesa la placa base con un **collar de laberinto** de 3 mm: el polvo de alimento no cae a la
  bahía electrónica.

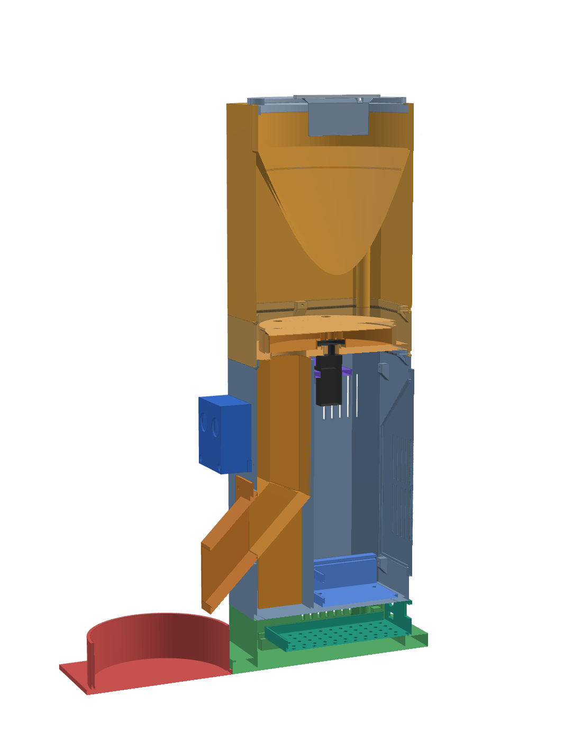
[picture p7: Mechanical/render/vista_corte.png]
Corte 3D


## 31. Piezas STL necesarias

Archivos en [`Mechanical/STL`](Mechanical/STL) (cada uno ya orientado para imprimir). Detalle de uniones, tornillos,
orientación y mantenimiento en [`Mechanical/README.md`](Mechanical/README.md).

| Pieza | Función | Ubicación | Dimensiones aprox. (mm) | Unión | Material |
|---|---|---|---|---|---|
| 01_Base_Torre | Energía + estabilidad | Abajo | 190×190×45 | 4 × M3 a través del piso de 02 | PLA/PETG |
| 02_Cuerpo_Principal | Canal, sensores, electrónica | Centro | 150×150×226 | Labio + 3 × M3 | PLA/PETG |
| 03_Modulo_HC_SR04 | Cápsula del sensor | Frente izq. | 52×58×28 | 2 × M3 + tuerca | PLA/PETG |
| 04_Modulo_ESP32_CAM | Cápsula de la cámara | Frente der. | 42×60×34 | 2 × M3 + tuerca | PLA/PETG |
| 05_Modulo_ESP32 | Bandeja de la placa del ESP32 | Bahía trasera | 100×74×29 | 4 × M3 + tuerca | PLA/PETG |
| 06_Soporte_MG995 | Viga del servo | Bajo el disco | 143×35×5 | 2 × M3 a ménsulas | PETG (rígido) |
| 07_Tolva | Depósito | Arriba | 150×150×180 | Labio + 3 × M3 | **PETG alimentario** |
| 08a_Carcasa_Dosificador | Anillo del módulo | Bajo la tolva | 150×150×44 | Labio + 3 × M3 | PLA/PETG |
| 08b_Disco_Dosificador | Disco de un bolsillo | Módulo 08 | Ø116×14 | Horn del MG995 | **PETG alimentario** |
| 08c_Placa_Superior_Dosificador | Entrada | Módulo 08 | Ø124×14 | Asiento cónico + chaveta | **PETG alimentario** |
| 08d_Placa_Base_Dosificador | Salida + cámara del disco | Módulo 08 | 143×143×32 | Apoyada y encajada | **PETG alimentario** |
| 09_Conducto_Alimento | Canal cerrado | Frente de 02 | 41×221×50 | Apoyado | **PETG alimentario** |
| 10_Salida_Alimento | Pico 45° | Frente | 64×106×52 | 4 × M3 | **PETG alimentario** |
| 11_Comedero | Plato | Delante | 150×146×44 | Lengüetas | **PETG alimentario** |
| 12a_Estacion_Solar_Base | Base con horquilla de la estación solar remota | Aparte, al sol | 130×110×70 | 4 tornillos o lastre; pivote M4 | **PETG/ASA (exterior)** |
| 12b_Estacion_Solar_Bandeja | Bandeja del panel (orientable 0–75°) | Aparte, al sol | 104×88×14 | 2 × M4×12 + tuercas alojadas | **PETG/ASA (exterior)** |
| 13a_Tapa_Superior_Tolva | Tapa con llave, avellanado para la cápsula y ranura del cable | Arriba | Ø146×13 | Encaje con llave | PETG |
| 13b_Capsula_Sensor_Nivel | Cápsula del HC-SR04 n.º 2 (transductores hacia el alimento) | Bajo la tapa | 54×64×31 | Ala a 45° en el avellanado | PETG |
| 13c_Tapa_Capsula_Sensor | Tapa de la cápsula | Sobre la tapa | 58×78×2 | 2 × M3×12 | PETG |
| 14_Tapa_Lateral_Servicio | Acceso a electrónica | Atrás de 02 | 109×186×6 | 4 × M3 | PLA/PETG |
| 15_Separadores | Separadores M3 | Varios | Ø7×3/6/10 | — | PLA/PETG |
| 16_Soporte_Estructural_Cajon_Energia | Cajón de energía | Base | 110×123×31 | 2 × M3 | PETG (calor) |

`00_Ensamblaje_Referencia_NO_IMPRIMIR.stl` muestra la torre completa (GitHub lo renderiza en 3D). Cómo armar cada pieza
impresa, paso a paso y con imágenes: [**manual de armado**](Documentation/manual_armado/Manual_de_Armado.md)
([PDF para imprimir](Documentation/manual_armado/Manual_de_Armado.pdf)).

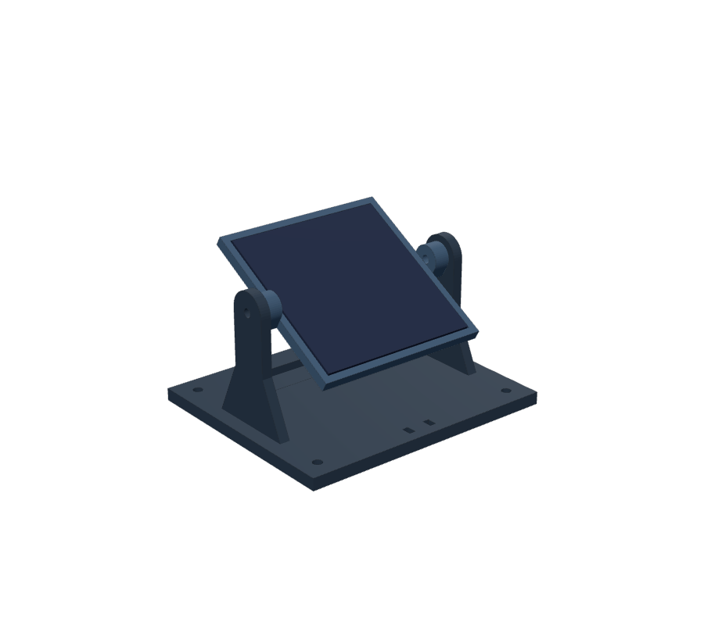
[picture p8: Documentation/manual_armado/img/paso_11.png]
Estación solar remota


## 32. Recomendaciones de impresión 3D

| Parámetro | Recomendación |
|---|---|
| Impresora | **Elegoo Neptune 4 Plus** (320 × 320 × 385 mm). Las 22 piezas se verifican con 5 mm de margen por lado (310 × 310 × 380); la más grande es la base (190 × 190) y la más alta el cuerpo (226 mm) |
| Placas | 5 placas agrupadas por material: [`Mechanical/plan_impresion.md`](Mechanical/plan_impresion.md) (generado por `plan_impresion.py`, que también lamina cada pieza con PrusaSlicer) |
| Capa / perímetros / relleno | 0,2 mm / 3 / 20 % giroide (40 % en 06, 08b, 12a, 12b, 16) |
| Grosor de pared del diseño | 3 mm (cuerpos), 2,5 mm (conducto, embudo), 2 mm (cápsulas) |
| Soportes | **Ninguno** (puentes ≤ 42 mm, voladizos ≤ 45°) |
| Tolerancias | 0,3 mm por lado en encajes; Ø3,4 pasante M3; Ø2,5 para roscar M3 en plástico |
| Materiales | PETG apto para alimentos en todo lo que toca el alimento (y en la tapa); PETG/ASA en la estación solar (exterior); PETG en 06 y 16; PLA en el resto |
| Calibración previa | Imprimir 06 y 15 primero y probar el servo y los tornillos |
| Filamento (laminado) | ≈ 1,0 kg de PLA + ≈ 1,25 kg de PETG; ≈ 86 h de impresión en total con velocidades moderadas |
| Higiene | Lavar a mano con agua tibia; secar; considerar un cuenco de acero inoxidable sobre 11 |

## 33. Tecnologías utilizadas

| Parte | Tecnología | Por qué |
|---|---|---|
| ESP32 | C++ / núcleo Arduino-ESP32 (2.x y 3.x), Arduino IDE o PlatformIO | Biblioteca madura de Wi-Fi, HTTP, LEDC (PWM) y ADC calibrado; fácil de defender y reproducir |
| ESP32 | ArduinoJson 7 | Lectura robusta de la respuesta JSON del PC (sin analizadores caseros) |
| ESP32-CAM | `esp_camera` (incluido en el núcleo), `WebServer` | Controlador oficial de la cámara; HTTP mínimo |
| PC | Python 3 + `http.server` de la biblioteca estándar | Sin frameworks web innecesarios |
| PC | OpenCV (`cv2`) | Decodificación, calidad de imagen, CLAHE, preprocesamiento y **ejecución de la red con `cv2.dnn`** |
| PC | MobileNetV2 (ONNX) | Modelo pequeño, preciso, licencia libre, funciona en CPU en decenas de ms |
| PC | NumPy | Normalización y suma de probabilidades |
| Mecánica | Python + manifold3d + trimesh | CAD paramétrico reproducible, con verificaciones automáticas |
| Impresión | PrusaSlicer (CLI) | Estimación real de filamento por pieza con un perfil equivalente al de la Neptune 4 Plus |
| Avisos al celular | ntfy (app gratuita + ntfy.sh) | Notificaciones push sin crear cuentas ni servidores propios; opcional |
| Pruebas | `unittest` (Python), g++ + stubs (firmware) | Verificación sin hardware |

## 34. Estructura del software

```
ESP32 (C++)                               PC (Python)                         ESP32-CAM (C++)
┌────────────────────────────┐          ┌──────────────────────────┐        ┌──────────────────┐
│ Dispensador_ESP32.ino      │          │ servidor_vision.py       │        │ Camara_ESP32CAM  │
│  └ HardwareReal ─┐         │  HTTP    │  ├ /classify  /status    │  HTTP  │  ├ /capture      │
│ Controlador (estados) ◀────┤ ───────▶ │  ├ /alerta  / (panel)    │ ─────▶ │  └ /status       │
│ Ultrasonico  Dosificador   │          │  └ ServicioVision        │        │ config.h         │
│ Energia      Red           │          │ clasificador.py (OpenCV) │        └──────────────────┘
│ NivelTolva   NivelGeometria│          │ alertas.py (ntfy)        │
│ config.h     secrets.h     │          │ config.py  model/        │
└────────────────────────────┘          └──────────────────────────┘
```

Separación de responsabilidades: **decisión** (Controlador) ≠ **hardware** (módulos) ≠ **red** (Red) en el ESP32;
**transporte** (servidor) ≠ **visión** (clasificador) ≠ **configuración** (config) en el PC.

## 35. Estructura de archivos

```
Proyecto-Dispensador-IOT/
├── README.md                          ← este documento
├── .github/workflows/verificacion.yml ← verificación automática en cada push (Python, STL, compilación real, QEMU)
├── ESP32/                             ← controlador
│   ├── Dispensador_ESP32/             (sketch: .ino + módulos .h/.cpp + config.h + secrets_ejemplo.h)
│   ├── test_host/                     (máquina de estados en PC, stubs, autoprueba en QEMU)
│   ├── platformio.ini
│   └── README.md
├── ESP32_CAM/                         ← cámara
│   ├── Camara_ESP32CAM/               (.ino + config.h + secrets_ejemplo.h)
│   ├── platformio.ini
│   └── README.md
├── OpenCV/                            ← visión artificial (PC)
│   ├── servidor_vision.py  clasificador.py  alertas.py  config.py
│   ├── descargar_modelo.py  probar_imagenes.py  capturar_dataset.py  simulador_camara.py  medir_red.py
│   ├── model/                         (modelo descargado, no se versiona)
│   ├── tests/                         (test_vision.py, test_modelo_real.py, descargar_imagenes_prueba.py)
│   ├── requirements.txt
│   └── README.md
├── Mechanical/                        ← diseño 3D
│   ├── generar_stl.py  render.py  plan_impresion.py
│   ├── STL/                           (22 piezas orientadas para imprimir + ensamblaje de referencia)
│   ├── render/                        (vistas, cortes y placas de impresión)
│   ├── plan_impresion.md              (placas para la Neptune 4 Plus, filamento y tiempo)
│   └── README.md
└── Documentation/
    ├── manual_armado/                 (Manual_de_Armado.md + .pdf + img/ con cada paso)
    ├── video/                         (video de funcionamiento y armado, guion, subtítulos y sus fuentes)
    ├── components/lista_materiales.csv (lista de compras)
    ├── wiring/                        (esquema completo + generador, tabla_conexiones.md, placa_control.* + generador)
    ├── power/calculo_energia.py
    └── calibration/                   (plantillas CSV + analizar_dosificacion.py)
```

## 36. Algoritmo

```
ALGORITMO Dispensador (ESP32)
  iniciar GPIO, ADC, HC-SR04, PWM; servo ← CERRADO; liberar servo
  conectar Wi-Fi (IP fija)
  estado ← ESPERANDO si hay Wi-Fi, si no ERROR_WIFI
  cada 50 ms:
    si error y botón BOOT ≥ 2 s: borrar errores
    si VBAT < 6,8 V: estado ← ERROR_ALIMENTACION
    si sin Wi-Fi: estado ← ERROR_WIFI
    según estado:
      ESPERANDO:   cada 60 s: nivel ← % de volumen de la tolva → alertas (3 lecturas, histéresis 20/30 %)
                   d ← mediana(3 disparos)
                   si zona libre ≥ 3 s: armar
                   si 3 ≤ d ≤ 35 cm (3 veces) y armado y sin cooldown: DETECTADO
      DETECTADO:   intentos ← 0; CAPTURANDO
      CAPTURANDO:  en la 1.ª foto: si cámara/status OK: PROCESANDO; si falla 2 veces: ERROR_CAMARA
                   en las siguientes: PROCESANDO directo (si la cámara falla, el PC responde 502)
      PROCESANDO:  r ← GET PC/classify (10 s)
                   200 → CLASIFICADO; 502 → ERROR_CAMARA; otro → ERROR_CLASIFICACION
      CLASIFICADO: si clase ∉ {1,2}:
                       si intentos+1 ≥ 5 o la mascota se fue: desarmar, ESPERANDO
                       si no, tras 2 s: intentos++, CAPTURANDO        (una foto cada ~2 s)
                   si clase ∈ {1,2}:
                       si deshabilitada o cooldown de clase o límite 24 h o tolva agotada: desarmar, ESPERANDO
                       si la mascota se fue: desarmar, ESPERANDO
                       si riel 6 V < 4,6 V: ERROR_SERVO
                       si no: DOSIFICANDO
      DOSIFICANDO: repetir CICLOS[clase] veces: LLENADO (+agitar, esperar) → DESCARGA (esperar, +agitar)
                   volver a CERRADO; liberar servo
                   atasco → ERROR_MECANISMO; sin riel → ERROR_SERVO; OK → FINALIZADO
      FINALIZADO:  registrar ración; desarmar; ESPERANDO
      errores:     reintentos/recuperación según §24

ALGORITMO /classify (PC)
  jpeg ← GET cámara/capture (3 s)   (si falla: 502 CAMARA_NO_RESPONDE)
  calidad (decodifica, tamaño, brillo, nitidez) → si válida: CLAHE → blob → cv2.dnn → softmax
  P(perro) = Σ p[151..268]; P(gato) = Σ p[281..285]
  si se ve un animal: promediar con las fotos de la visita (últimos 5 s, máx. 3)
  decidir (mínimo animal 0,5; confianza 0,6; margen 0,3) → 1, 2 o 0; con 1 o 2 la visita termina
  responder JSON; guardar las fotos con la etiqueta (registro para calibrar)

ALGORITMO /alerta (PC)
  validar el tipo; guardar (últimas 50); mostrar en el panel web; si hay tema ntfy: enviar al celular en segundo plano
```

## 37. Código propuesto

El código completo y comentado está en el repositorio (no se duplica aquí):

| Archivo | Contenido |
|---|---|
| [`ESP32/Dispensador_ESP32/config.h`](ESP32/Dispensador_ESP32/config.h) | Pines, red, umbrales, tiempos y dosis |
| [`ESP32/Dispensador_ESP32/Controlador.cpp`](ESP32/Dispensador_ESP32/Controlador.cpp) | Máquina de estados |
| [`ESP32/Dispensador_ESP32/Dosificador.cpp`](ESP32/Dispensador_ESP32/Dosificador.cpp) | PWM, rampa, ciclo de dosis, anti-atasco |
| [`ESP32/Dispensador_ESP32/Ultrasonico.cpp`](ESP32/Dispensador_ESP32/Ultrasonico.cpp) | HC-SR04 |
| [`ESP32/Dispensador_ESP32/Red.cpp`](ESP32/Dispensador_ESP32/Red.cpp) | Wi-Fi, HTTP, JSON |
| [`ESP32/Dispensador_ESP32/Dispensador_ESP32.ino`](ESP32/Dispensador_ESP32/Dispensador_ESP32.ino) | Integración, `/status`, comandos de calibración |
| [`ESP32_CAM/Camara_ESP32CAM/Camara_ESP32CAM.ino`](ESP32_CAM/Camara_ESP32CAM/Camara_ESP32CAM.ino) | Cámara + HTTP |
| [`OpenCV/clasificador.py`](OpenCV/clasificador.py) | Calidad, OpenCV DNN, decisión 1/2/0 |
| [`ESP32/Dispensador_ESP32/NivelTolva.cpp`](ESP32/Dispensador_ESP32/NivelTolva.cpp) | Sensor de nivel: medición, calibración en NVS, % de volumen |
| [`OpenCV/servidor_vision.py`](OpenCV/servidor_vision.py) | Servidor `/classify`, `/status`, `/alerta` y panel web |
| [`OpenCV/alertas.py`](OpenCV/alertas.py) | Alertas de nivel y reenvío al celular (ntfy) |

Fragmento clave del ESP32 (decisión antes de mover el servo, `Controlador.cpp`):

```cpp
case Estado::CLASIFICADO: {
  const int c = ultimaClase_;
  if (c != CLASE_PERRO && c != CLASE_GATO) {          // 0 = INDETERMINADO: nunca dispensa
    ...reintenta como máximo 3 veces si la mascota sigue delante...
  }
  if (!racionPermitida(c, porque, sizeof(porque))) { volverAEsperar(porque); break; }
  if (!mascotaPresente(hw_.distanciaCm())) { volverAEsperar("la mascota abandono el area"); break; }
  if (p_.usarMonitorServo && hw_.voltajeServo() < p_.vservoMin) { cambiarA(Estado::ERROR_SERVO, ...); break; }
  cambiarA(Estado::DOSIFICANDO, ...);
}
```

Fragmento clave del PC (OpenCV + modelo, `clasificador.py`):

```python
blob = cv2.dnn.blobFromImage(img_bgr, 1/255.0, (224, 224), (0, 0, 0), swapRB=True, crop=False)
blob = ((blob - MEDIA) / DESV).astype(np.float32)
self.red.setInput(blob)
prob = softmax(self.red.forward())
p_perro, p_gato = prob[151:269].sum(), prob[281:286].sum()
```

**Puesta en marcha rápida:**

```bash
# PC
cd OpenCV && pip install -r requirements.txt && python descargar_modelo.py
python servidor_vision.py --camara http://192.168.1.51 --esp32 http://192.168.1.52   # + --ntfy TEMA (opcional)
# Panel web con el nivel de la tolva y las alertas: http://IP-DEL-PC:8000/
# ESP32 y ESP32-CAM: copiar secrets_ejemplo.h -> secrets.h, revisar IP en config.h y cargar
# Sensor de nivel: con la tolva vacía NIVEL VACIO; con alimento en el surco MAX NIVEL LLENO (monitor serie)
```

## 38. Plan de pruebas

Registrar cada prueba (fecha, valores, foto). **Prueba 0** (añadida): alimentación, antes de conectar cualquier módulo.

| Prueba | Objetivo | Procedimiento | Resultado esperado | Criterio de aprobación | Errores posibles | Solución |
|---|---|---|---|---|---|---|
| **0. Energía** | Rieles correctos y seguros | Sin cargas: ajustar Buck A y B; medir VBAT, 6 V, 5 V; luego con cargas | 6,0 ± 0,1 V y 5,0–5,1 V | Tensiones dentro de rango, sin calentamiento en 10 min | Buck sin ajustar, polaridad invertida | Ajustar/medir antes de conectar; revisar polaridad |
| **1. HC-SR04** | Medición y nivel de ECHO | Medir con multímetro ≈3,3 V en GPIO34 al disparar; `DIST` a 10/20/30/40 cm (5 lecturas) | Lecturas ± 1 cm, mediana estable | Error ≤ 1,5 cm hasta 40 cm; ECHO ≤ 3,4 V en el pin | Sin eco (-1), lecturas 0, divisor invertido | Revisar R1/R2 y 5 V; separar de superficies blandas |
| **2. ESP32-CAM** | Captura | Navegador: `http://192.168.1.51/capture` y `/status` 20 veces | JPEG nítido en < 1 s | 20/20 fotos válidas, sin reinicios | Brownout, `0x105` (cámara), sin Wi-Fi | Fuente y condensadores; cinta FPC; red 2,4 GHz |
| **3. MG995** | Movimiento y alimentación | `SERVO 1500`, `1000`, `2000`; medir corriente con amperímetro en serie | Movimiento suave, se queda quieto | Sin vibración, riel ≥ 5,8 V durante el giro, ESP32 no se reinicia | Vibra, no se mueve, es de 360° | GND común, 74AHCT125, condensador, cambiar a 180° |
| **4. Wi-Fi** | Conectividad | Encender los 3 equipos; `ping` a cada IP; `/status` del ESP32 | Responden los 3 | RSSI > -75 dBm; reconexión < 30 s tras apagar el router | IP duplicada, red 5 GHz | Ajustar IP/subred; usar 2,4 GHz |
| **5. OpenCV** | Clasificación | `python -m unittest`; `probar_imagenes.py dataset --barrido` con fotos de la cámara | Matriz de confusión casi diagonal | **0 decisiones peligrosas** (perro↔gato o dispensar a "otros") y ≥ 90 % de perros/gatos detectados | Umbrales altos/bajos, mala luz | Recalibrar umbrales; iluminar; CLAHE |
| **6. ESP32 ↔ PC** | Integración | Comando `CLASIFICAR` con perro, gato, nada; apagar la cámara; apagar el PC | Clase correcta; ERROR_CAMARA; ERROR_CLASIFICACION | Las 5 situaciones con el estado correcto y recuperación automática | Firewall del PC, IP del PC errónea | Abrir puerto 8000; corregir `URL_PC` |
| **7. Dosificación** | Repetibilidad | Calibrar posiciones; `CICLO 1` × 10 con tolva llena/media/baja; pesar; forzar un atasco con una croqueta grande | g/ciclo estable; atasco detectado | CV ≤ 10 %; ninguna caída de alimento fuera del conducto; atasco → ERROR_MECANISMO y servo liberado | Bolsillo no se llena, puenteo en tolva, sin detección de atasco | Aumentar T_LLENADO; agitación; ajustar VSERVO_CAIDA |
| **8. Sistema completo** | Funcionamiento real | 20 aproximaciones (perro/peluche, gato/foto, persona, nadie); 1 h continua con batería | Dispensa solo a perro/gato, respeta cooldown | 0 dispensaciones indebidas; ≥ 90 % correctas; sin reinicios en 1 h | Repeticiones, reinicios | Ajustar cooldown/rearmado; revisar alimentación |
| **R. Red local** (añadida) | Rapidez sin Internet | Red propia (router o celular sin datos); `python medir_red.py --clasificar`; 10 aproximaciones midiendo el tiempo hasta la decisión | Decisión en menos de 1–2 s después de que el sensor confirma | Mediana de `/classify` < 2 s y ninguna respuesta perdida | Señal débil, IP equivocada | Acercar el router, red 2,4 GHz, revisar las IP |
| **9. Sensor de nivel** (añadida) | Alertas de comida | Calibrar VACIO/LLENO; `NIVEL` con tolva llena, media y casi vacía; vaciar hasta < 20 % y < 3 % | ≈ 100 % lleno; alerta en el panel web (y celular) | Alerta en ≤ 3 min al cruzar el 20 %; con ≤ 3 % no dispensa; al recargar llega COMIDA_REPUESTA | "Sin lectura", saltos | Revisar J5/cable; nivelar el alimento; recalibrar |
| **E. Panel** (añadida) | Aporte real | Estación al sol; medir V<sub>oc</sub>, I<sub>sc</sub>; `v_panel` en `/status`; corriente de carga | ≈ 0,3 W pico al sol, ≈ 0 en interior | Medición registrada y coherente con §21 | Elevador oscila; GX12 invertido | Documentarlo; mejora con MPPT; pin 1 = + |

**Pruebas ya ejecutadas sin hardware (reproducibles; también corren solas en GitHub Actions en cada `push`):**

```bash
cd OpenCV && python -m unittest discover -s tests -v      # 29 pruebas (la del modelo real se activa con imágenes)
cd OpenCV && python medir_red.py --clasificar             # tiempos de la red local (con el hardware encendido)
python tests/descargar_imagenes_prueba.py imagenes_prueba && \
  DISPENSADOR_IMAGENES_PRUEBA=imagenes_prueba python -m unittest tests.test_modelo_real -v   # 25 imágenes, 0 peligrosas
cd ESP32/test_host && make                                # 26 escenarios de la máquina de estados
cd ESP32/test_host && make sintaxis                       # compilación rápida contra stubs (API 2.x y 3.x)
arduino-cli compile --fqbn esp32:esp32:esp32doit-devkit-v1 ESP32/Dispensador_ESP32           # compilación real
arduino-cli compile --fqbn esp32:esp32:esp32cam:PartitionScheme=huge_app ESP32_CAM/Camara_ESP32CAM
ESP32/test_host/qemu_autoprueba.sh ...                    # firmware real en el emulador QEMU (ver ESP32/README.md)
cd Mechanical && python generar_stl.py                    # 45 verificaciones geométricas (incl. Neptune 4 Plus)
cd Mechanical && python plan_impresion.py                 # placas + filamento (PrusaSlicer opcional)
python Documentation/wiring/generar_placa_control.py      # placa de control coherente con config.h
python Documentation/wiring/generar_esquema.py            # esquema completo desde config.h
```

## 39. Problemas posibles

| Problema | Causa posible |
|---|---|
| ESP32 se reinicia | Caída del 5 V cuando se mueve el servo; servo alimentado desde el ESP32; USB débil; Wi-Fi TX sin condensadores |
| MG995 vibra | Sin GND común; tensión baja; ruido en la señal; nivel 3,3 V insuficiente en esa unidad; pulso fuera de rango; servo de mala calidad (clon) |
| MG995 gira sin parar | Es la versión de 360° (giro continuo) |
| HC-SR04 falla (-1 o lecturas erráticas) | ECHO sin divisor o divisor invertido; sin 5 V; pelaje que absorbe; ángulo; ecos del comedero |
| ESP32-CAM no responde | Brownout; cinta FPC suelta; Wi-Fi 5 GHz; IP distinta; PSRAM desactivada en el IDE |
| OpenCV no clasifica | Modelo no descargado; foto oscura/borrosa; mascota fuera de encuadre; umbrales inadecuados |
| Clasifica mal | Iluminación; fondo confuso; razas poco representadas; fotos en pantallas o peluches |
| Alimento se atasca | Croqueta > 14 mm; humedad; bóveda en la tolva; pellizco en la entrada; servo trabado |
| Cae alimento sin ordenarlo | Bolsillo conectando entrada y salida (posiciones mal calibradas); placa superior mal asentada |
| Panel insuficiente | Panel de 0,3 W frente a 1,7 W de consumo (esperado); interior sin sol |
| Batería se agota rápido | Celdas de capacidad falsa; 2S1P; Wi-Fi siempre activo |
| Raciones repetidas | Cooldown muy corto; rearmado demasiado sensible |
| PC no recibe peticiones | Firewall; IP del PC cambió (DHCP); servidor no iniciado |
| La torre se vuelca | Mascota grande; sin lastre; tolva llena arriba |
| No llega la alerta de comida | Sensor de nivel sin calibrar; cable de J5 suelto; PC apagado; ntfy sin Internet o tema mal escrito |
| El nivel salta o marca mal | Alimento amontonado bajo el sensor; tapa girada (sin llave); llenado por encima del surco MAX (< 2 cm del sensor) |
| `v_panel` en 0 al sol | GX12 desenchufado o con la polaridad invertida; cable cortado en el exterior |

## 40. Soluciones

| Problema | Solución |
|---|---|
| ESP32 se reinicia | Servo **solo** desde Buck A; condensadores 1000–2200 µF y 470 µF; GND estrella; no desactivar brownout |
| MG995 vibra | GND común; 6,0 V con cable corto; 330 Ω + pull-down; buffer 74AHCT125 si persiste; recalibrar pulsos dentro de 500–2500 µs |
| MG995 gira sin parar | Cambiar por la versión de 180° (o rediseñar a dosificación por tiempo, menos precisa) |
| HC-SR04 falla | Verificar 3,3 V en GPIO34; 5 V en VCC; alejar del comedero; ajustar `DIST_*`; usar mediana |
| ESP32-CAM no responde | 470 µF + 100 nF; revisar FPC; red 2,4 GHz; verificar IP; reinicio automático incluido |
| OpenCV no clasifica | `python descargar_modelo.py`; mejorar luz; re-encuadrar la cápsula; recalibrar umbrales con `--barrido` |
| Clasifica mal | Dataset propio con la cámara instalada; si no alcanza, reentrenar (transfer learning) con fotos de las mascotas |
| Alimento se atasca | Grano ≤ 14 mm o agrandar `D_BOLSILLO`; alimento seco; tolva ≥ 55°; retroceso automático; limpiar y `RESET` |
| Cae alimento sin ordenarlo | Recalibrar posiciones con las marcas; asentar 08c con su chaveta |
| Panel insuficiente | Batería + carga USB (diseño actual); para autonomía: panel ≈ 14 W + MPPT 2S, o apagar la cámara entre detecciones |
| Batería se agota | Celdas reales; 2S2P (≈ 17 h); cargar antes de la feria |
| Raciones repetidas | Subir `COOLDOWN_*`, `ZONA_LIBRE_MS`, bajar `MAX_RACIONES_DIA_*` |
| PC no recibe peticiones | Abrir puerto 8000; IP fija/reservada; iniciar `servidor_vision.py` |
| La torre se vuelca | Lastre en la base; fijar a una tabla o pared; tolva llena solo hasta la mitad en pruebas |
| No llega la alerta de comida | `NIVEL VACIO`/`NIVEL LLENO`; revisar J5 (GND-ECHO-TRIG-VCC); `alerta_pendiente` en `/status`; panel web del PC; tema ntfy |
| El nivel salta o marca mal | Nivelar el alimento; colocar la tapa con la llave atrás a la izquierda; no llenar sobre MAX; recalibrar |
| `v_panel` en 0 al sol | Enchufar el GX12 con S1 apagado; comprobar pin 1 = + con el multímetro |

## 41. Lista de verificación

**Antes de colocar el ESP32 en la placa de control**
- [ ] Los 34 cables de `placa_control.md` soldados y tachados
- [ ] Sin continuidad entre 5V y GND, ni entre ECHO_5V (R1) / ECHO2_5V (R5) y los pines D34 / D21
- [ ] Con J1 alimentado y los HC-SR04 conectados: ≤ 3,4 V en los agujeros de D34 y D21 al disparar

**Antes de conectar la batería**
- [ ] Buck A = 6,0 V y Buck B = 5,0 V medidos sin carga
- [ ] BMS cableado (B+, BM, B−) y fusible de 4 A en P+
- [ ] Ningún cable de 6–8,4 V llega a un GPIO
- [ ] Divisores de los ECHO: 1 kΩ en serie, 2 kΩ a GND (R1/R2 y R5/R6, medidos con el óhmetro)
- [ ] GX12 del panel: pin 1 = + (medido al sol antes de enchufar)
- [ ] GND común entre convertidores, ESP32, ESP32-CAM, HC-SR04 y MG995

**Antes de cargar alimento**
- [ ] Servo es versión 180° y se queda quieto en cada posición
- [ ] Posiciones LLENADO/DESCARGA/CERRADO calibradas con las marcas
- [ ] Disco gira libre; placa superior asentada con su chaveta
- [ ] Conducto y pico montados; el alimento cae en el comedero (prueba con 5 ciclos)
- [ ] Tapa con la llave en su ranura; `NIVEL VACIO` y `NIVEL LLENO` calibrados; no llenar sobre el surco MAX

**Antes de la demostración**
- [ ] Router/punto de acceso 2,4 GHz y las tres IP verificadas
- [ ] `servidor_vision.py` corriendo, puerto 8000 permitido
- [ ] Umbrales calibrados con la iluminación del lugar
- [ ] `MODO_FERIA 1` y cooldown adecuados
- [ ] Batería cargada (VBAT ≥ 8,0 V) y comedero limpio
- [ ] Estación solar al sol (o junto a una ventana) con el GX12 enchufado
- [ ] Panel web del PC abierto (`http://IP-DEL-PC:8000/`) para mostrar el nivel y las alertas

## 42. Auditoría técnica final

Leyenda: ✅ verificado en este repositorio · 🔧 verificado en diseño, **pendiente de comprobación física** (plan §38).

**ELECTRÓNICA**
- ✅ Pines verificados (§15, §19): sin pines de flash, UART ni arranque para funciones críticas.
- ✅ No existen conflictos GPIO (una función por pin; ADC solo en ADC1).
- ✅ Voltajes compatibles: 5 V solo en VIN/5V/VCC; 6,0 V solo en el servo; 8,4 V solo en entradas de convertidores y divisores.
- ✅ Niveles lógicos compatibles: TRIG 3,3 V ≥ V<sub>IH</sub> TTL; los dos ECHO 3,33 V ≤ 3,6 V (R1/R2 y R5/R6). 🔧 Señal del servo a 3,3 V (plan B: 74AHCT125).
- ✅ GND correctamente definido (punto estrella, GND junto a la señal del servo).
- ✅ MG995 correctamente alimentado (Buck A exclusivo, ≥ 3 A, nunca desde GPIO ni batería directa).
- ✅ ESP32 correctamente alimentado (5 V regulados por VIN). 🔧 Diodo USB-VIN según el clon.
- ✅ ESP32-CAM correctamente alimentada (5 V + condensadores).
- ✅ HC-SR04 de presencia y de nivel correctamente conectados (5 V + divisor; GPIO26/34 y GPIO19/21).
- ✅ Panel en estación remota con conector polarizado; caída en 5 m de cable ≈ 0,05 V (calculada).
- ✅ No existen conexiones potencialmente peligrosas en el esquema (fusible, BMS, interruptor, divisores en origen).

**SOFTWARE**
- ✅ ESP32 controla el sistema y toma la decisión final (26 escenarios probados en PC, 5 del sensor de nivel y 2 de
  las fotos cada 2 s).
- ✅ Fotos en vez de video: la cámara en modo foto no captura de forma continua; una foto cada ~2 s solo con la
  mascota delante (máx. 5) y las fotos de la visita se combinan (probado con visitas simuladas en el PC).
- ✅ Funcionamiento local: ningún paso de la identificación usa Internet (§13.5). 🔧 Medir los tiempos en la red real
  con `medir_red.py`.
- ✅ Alerta de comida por acabarse: ESP32 → `POST /alerta` → panel web y celular (probado de punta a punta con un
  servidor ntfy simulado); reenvío si el PC no la recibe; un sensor roto no bloquea la alimentación.
- ✅ ESP32-CAM captura imágenes (`/capture`). ✅ Ambos firmwares compilan con la cadena oficial de Espressif
  (núcleos 2.0.17 y 3.0.7) y el del ESP32 arranca y funciona en el emulador QEMU. 🔧 Cámara y Wi-Fi reales.
- ✅ Python recibe/procesa imágenes (prueba extremo a extremo HTTP con cámara simulada).
- ✅ OpenCV participa realmente (decodificación, calidad, CLAHE, blob y ejecución de la red con `cv2.dnn`).
- ✅ La clasificación devuelve 1 o 2 (y 0 cuando no debe dispensarse; probado con 2000 casos aleatorios).
- ✅ Comunicación definida (HTTP, IP, endpoints, JSON, códigos, timeouts, reconexión).
- ✅ Manejo de errores (17 situaciones, §25).
- ✅ Máquina de estados definida (§24) y probada.

**MECÁNICA**
- ✅ Tolva (≈ 632 cm³ útiles hasta el surco MAX, paredes ≥ 55°), con sensor de nivel en la tapa (cápsula fuera del
  alimento, alcance mínimo respetado, tabla altura → volumen verificada contra el firmware).
- ✅ Mecanismo (disco volumétrico, sin paso directo tolva→canal, margen 15°).
- ✅ MG995 (soporte con ranuras, sin interferencias con ninguna pieza).
- ✅ Conducto (cerrado, más ancho que la salida).
- ✅ Salida (la punta cae dentro del comedero y por encima de su borde).
- ✅ Comedero (encastrado, desmontable).
- ✅ Separación entre electrónica y alimento (verificada por intersección de volúmenes).
- ✅ Torre modular (5 niveles, 19 piezas + separadores, tornillería M3) y estación solar remota (2 piezas, pivote M4,
  bandeja libre de 0° a 75°).
- ✅ Mantenimiento (cajón, tapa de servicio, bandeja deslizante, piezas de alimento desmontables a mano).
- ✅ Piezas imprimibles en la **Elegoo Neptune 4 Plus** (las 22 caben con margen; 5 placas; sin soportes; filamento
  calculado laminando cada pieza). ✅ Manual de armado paso a paso. 🔧 Ajuste fino de cotas de componentes con calibre.

**ENERGÍA**
- ✅ Panel solar analizado (0,3 W, no 1 W).
- ✅ Potencia calculada (1,75 W medios; picos 0,59 A en 5 V, 2,5 A en 6 V, 3,3 A en batería).
- ✅ Consumo analizado (42,0 Wh/día, incluye el segundo HC-SR04) con script reproducible. 🔧 Medir consumos reales.
- ✅ Almacenamiento analizado (2S1P ≈ 8,5 h; 2S2P ≈ 17 h).
- ✅ Regulación analizada (Buck 6,0 V y 5,0 V; caída de tensión en batería baja dentro del rango del MG995).
- ✅ MG995 no depende directamente del GPIO.
- ✅ No existen afirmaciones físicamente imposibles: el panel **no** alimenta el sistema; se explica cuánto aporta y qué haría falta.

**Datos que faltan para garantizar el 100 % de la conexión física** (deben medirse o leerse en su unidad):
modelo exacto del HC-SR04 (5 V o "P"), versión del MG995 (180° o 360°) y su rango real de pulsos, presencia de diodo
USB-VIN en su DevKit, V<sub>oc</sub>/I<sub>sc</sub> y dimensiones del panel, capacidad real de las celdas, corriente
máxima del cargador 2S y del BMS elegidos, tamaño de las croquetas, altura de los transductores del HC-SR04 de la tolva
y densidad aparente del alimento (para pasar el % de volumen a gramos).

---

### Explicación sencilla para la presentación

* **Qué problema resuelve:** alimentar a perros y gatos de forma automática, con la ración correcta para cada uno y sin
  que el mismo animal vacíe el depósito.
* **Cómo funciona:** "el sensor ve que alguien se acerca, la cámara le saca una foto, la computadora dice si es perro o
  gato, y el ESP32 decide si le da comida y cuánta".
* **IoT:** tres dispositivos (ESP32, ESP32-CAM, PC) que se comunican por Wi-Fi con HTTP y se pueden monitorear (`/status`).
  Todo es **local**: la foto nunca sale de la sala ni pasa por Internet (pregunta del profesor).
* **Cámara:** no graba video; cuando llega la mascota saca una foto cada 2 s hasta reconocerla (idea del profesor).
* **Visión artificial:** OpenCV prepara y evalúa la imagen y ejecuta una red neuronal (MobileNetV2) que reconoce perros y
  gatos; si duda, no dispensa.
* **Automatización:** máquina de estados con reglas de seguridad, dosificación por ciclos calibrados y manejo de errores.
* **Aviso de comida (idea del profesor):** un segundo sensor ultrasónico en la tapa mide cuánto alimento queda; cuando
  baja del 20 % el ESP32 avisa a la computadora y al celular, y si se vacía deja de "servir" en vacío.
* **Por qué ESP32:** Wi-Fi integrado, PWM y ADC, barato, programable en C++. **Por qué ESP32-CAM:** cámara + Wi-Fi en un
  módulo pequeño. **Por qué OpenCV:** estándar de la industria, ejecuta redes neuronales en CPU. **Por qué HC-SR04:**
  detección simple y barata que evita tener la cámara y el PC trabajando todo el tiempo. **Por qué MG995:** par alto
  (10 kgf·cm) y engranajes metálicos.
* **Sistema solar:** el panel está en una estación aparte, donde hay sol (idea del profesor), y por un cable carga una
  batería a través de un elevador y un cargador; se demuestra y se mide, y se explica con números por qué un panel de
  0,3 W no puede mover el sistema (consume 1,75 W).
* **La torre:** módulos que se apilan; el alimento baja por una columna cerrada al frente y la electrónica vive atrás y
  abajo, separada.
* **La dosificación:** un disco con un hueco hace de "cucharita" de volumen fijo; la balanza dice cuántos gramos son.

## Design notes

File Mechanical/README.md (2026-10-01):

# Mecánica — Torre modular imprimible en 3D (Elegoo Neptune 4 Plus)

Vista frontal

Todo el modelo es **paramétrico** y se genera con Python:

```bash
pip install numpy trimesh manifold3d matplotlib
python generar_stl.py      # crea STL/ (piezas ya orientadas) y ejecuta 45 verificaciones automáticas
python plan_impresion.py   # placas para la Neptune 4 Plus + filamento y tiempo (lamina con PrusaSlicer si está)
python render.py           # planos 2D: corte del recorrido del alimento y planta del dosificador
```

**Armado:** [manual paso a paso con imágenes](../Documentation/manual_armado/Manual_de_Armado.md)
([PDF](../Documentation/manual_armado/Manual_de_Armado.pdf)).

`generar_stl.py` comprueba en cada ejecución (también en GitHub Actions):

* que **ninguna pieza interfiera con otra** (19 piezas de la torre, 171 pares) ni con la envolvente del MG995;
* que el bolsillo del disco **nunca conecte** la tolva con el conducto a la vez (margen angular);
* que el interior del canal de alimento **no contenga electrónica** (ESP32, ESP32-CAM, HC-SR04, MG995, soporte);
* que la punta del pico caiga dentro del comedero y por encima de su borde;
* que las paredes de la tolva tengan **≥ 55°** (las croquetas no forman bóveda con paredes tendidas);
* **sensor de nivel:** surco MAX a ≥ 2 cm de los transductores (alcance mínimo del HC-SR04), cápsula por encima del
  alimento, HC-SR04 dentro de la cápsula, y que la tabla altura → volumen del firmware (`NivelGeometria.h`) coincida con
  esta tolva; informa a qué altura y cuánto alimento corresponden los umbrales de `config.h`;
* **estación solar:** que la bandeja gire de 0° a 75° sin tocar la base;
* que **las 22 piezas quepan en la Elegoo Neptune 4 Plus** (320 × 320 × 385 mm; se exige 310 × 310 × 380 para dejar
  margen a la falda) y tengan una cara plana de apoyo en la orientación de impresión.

> Las cotas de los componentes comprados (MG995, HC-SR04, ESP32-CAM, placa perforada, panel) son las
> **nominales** y están al principio de `generar_stl.py` (sección COMPONENTES). **Mida sus unidades con un
> calibre** y corrija esos parámetros antes de imprimir: los clones varían. El panel solar debe medirse sí o sí
> (`PANEL_W`, `PANEL_H`, `PANEL_E`).

## Piezas

`STL/` contiene cada pieza **ya orientada para imprimir** y `00_Ensamblaje_Referencia_NO_IMPRIMIR.stl`
(GitHub lo muestra en 3D).

| Pieza | Función / ubicación | Tamaño de impresión (mm) | Unión y tornillería | Orientación | Mantenimiento |
|---|---|---|---|---|---|
| 01_Base_Torre | Módulo de energía; plinto de 190 mm para estabilidad; 4 pilares de unión | 190×190×45 | 4 × M3×12 desde arriba (a través del piso de 02) | Como está | Se separa de 02 quitando 4 tornillos |
| 16_Soporte_Estructural_Cajon_Energia | Cajón deslizante: batería, BMS, convertidores, cargador; tapa trasera con interruptor, USB-C y **conector GX12 del panel remoto** | 110×123×31 | 2 × M3×10 a tetones de 01; componentes con M3 + separadores (rejilla 10 mm) | Piso abajo | Sale por detrás sin desarmar la torre |
| 02_Cuerpo_Principal | Canal de alimento (frente), tabique, bahía electrónica (atrás), frente de sensores | 150×150×226 | Labio superior + 3 × M3×10 radiales hacia 08a | Como está | Tapa de servicio trasera |
| 03_Modulo_HC_SR04 | Cápsula del HC-SR04 de presencia (horizontal, pines abajo) | 52×58×28 | 2 × M3×10 + tuerca por dentro de la pared | Cara frontal abajo | Se desatornilla desde el frente |
| 04_Modulo_ESP32_CAM | Cápsula de la ESP32-CAM, inclinada 12° hacia abajo, con ventilación | 42×60×34 | 2 × M3×10 + tuerca | Cara frontal abajo | Se desatornilla desde el frente |
| 05_Modulo_ESP32 | Bandeja con guías para una placa perforada 90×70 mm con el ESP32 | 100×74×29 | 4 × M3×10 + tuerca bajo el piso | Como está | La placa sale deslizando por la tapa trasera |
| 06_Soporte_MG995 | Viga que sostiene el servo, apoyada en dos ménsulas de 02 | 143×35×5 | 2 × M3×10 a las ménsulas; servo con 4 tornillos en ranuras | Plana | Calces (15) para ajustar la altura |
| 07_Tolva | Depósito con embudo cónico oblicuo (≥55°), **surco MAX** de llenado, ranura de la llave de la tapa y tubo cerrado en la esquina trasera izquierda para el cable del sensor de nivel | 150×150×180 | Sobre el labio de 08a + 3 × M3×10 | Como está | Se retira para limpiar; sin electrónica |
| 08a_Carcasa_Dosificador | Anillo exterior del módulo dosificador | 150×150×44 | Labio de 02 + 3 × M3×10; labio para 07 | Como está | — |
| 08b_Disco_Dosificador | Disco de 116 mm con un bolsillo de Ø28×14 mm (8,6 cm³ geométricos) | 116×116×14 | Atornillado al horn redondo del MG995 | Boca abajo | Se saca levantando 08c |
| 08c_Placa_Superior_Dosificador | Tapa del disco con la entrada (Ø28) y zócalo para la boca de la tolva | 124×124×14 | Asiento cónico + chaveta (sin tornillos) | Como está | Sale a mano para limpiar |
| 08d_Placa_Base_Dosificador | Placa con la salida (Ø32), cámara del disco, laberinto del eje, tubo de cables y marcas de calibración | 143×143×32 | Apoya sobre el labio de 02, encajada en 08a | Como está | Superficie lisa, lavable |
| 09_Conducto_Alimento | Tubo cerrado 36×36 mm: vertical + codo a 45° hacia el frente | 41×221×50 | Apoya en el piso de 02; se baja desde arriba | Acostado sobre su cara trasera | Se lava; se cepilla por dentro |
| 10_Salida_Alimento | Pico a 45° que deja caer el alimento en el comedero | 64×106×52 | 4 × M3×10 a tetones del frente de 02 | Sobre la cara inferior del tubo | Se desmonta desde fuera |
| 11_Comedero | Plato con cuenco Ø118 interior; 2 lengüetas que entran bajo el plinto | 150×146×44 | Encastre (sin tornillos) | Como está | Se saca para lavar (ver nota de higiene) |
| **12a_Estacion_Solar_Base** | Base de la **estación solar remota**: horquilla con pivote M4, bolsillo de lastre, 4 agujeros de fijación y paso de brida para el cable | 130×110×70 | 4 tornillos Ø4 o lastre | Como está | — |
| **12b_Estacion_Solar_Bandeja** | Bandeja del panel (alojamiento paramétrico + ventana para soldaduras); nudillos con **tuerca M4 alojada** | 104×88×14 | 2 × M4×12 + arandela; fija el ángulo por fricción (0–75°) | Como está | Se reorienta aflojando los M4 |
| **13a_Tapa_Superior_Tolva** | Tapa con **llave** (una sola posición), muescas para los dedos, avellanado a 45° para la cápsula, 2 tetones y **ranura del cable** hacia el tubo de la esquina | 146×145×13 | Encaje con llave | Boca abajo | Se levanta para cargar; el cable tiene holgura |
| **13b_Capsula_Sensor_Nivel** | Cápsula del **HC-SR04 n.º 2**: dos agujeros Ø16,8 para los transductores, nervios de apoyo de la placa, ala a 45° y muesca del cable | 54×64×31 | Cuelga del avellanado de 13a | Piso abajo | Sale desde arriba quitando 13c |
| **13c_Tapa_Capsula_Sensor** | Tapa de la cápsula | 58×78×2 | 2 × M3×12 a los tetones de 13a | Plana | — |
| 14_Tapa_Lateral_Servicio | Tapa trasera de la bahía electrónica (ventilada) | 109×186×6 | 4 × M3×10 | Cara exterior abajo | Acceso al ESP32, servo y cableado |
| 15_Separadores | Tubos para M3 (3, 6 y 10 mm) | 67×19×10 | — | Como está | — |

**Recorrido del alimento:** 07 → 08c (entrada) → 08b (bolsillo) → 08d (salida) → 09 → 10 → 11.
Ninguna de esas piezas contiene ni toca electrónica.

Corte

### Sensor de nivel en la tapa (recomendación del profesor)

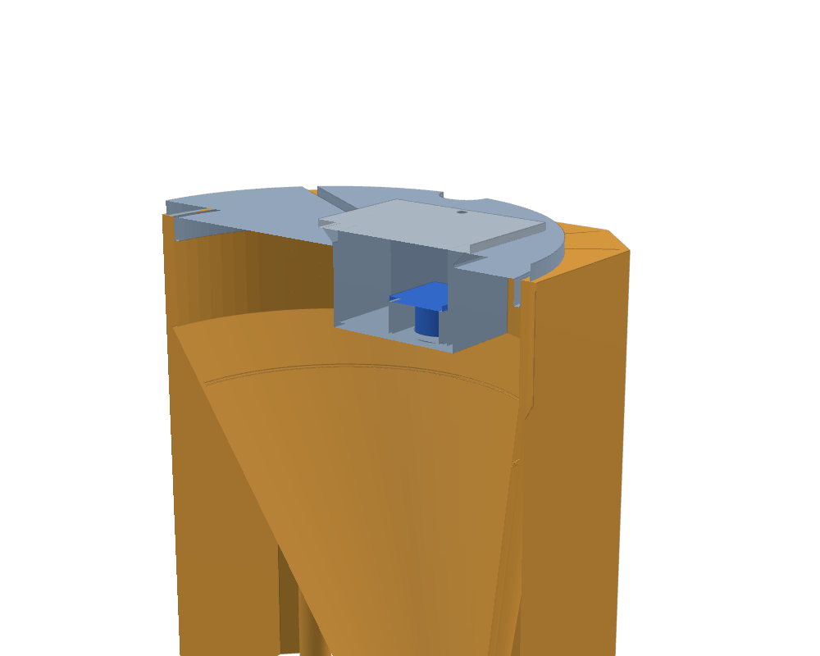
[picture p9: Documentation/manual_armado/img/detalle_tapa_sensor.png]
Detalle de la tapa con el sensor de nivel


La cápsula 13b es una pieza aparte para que se imprima **sin puentes** (piso sobre la cama) y para poder cambiar el
sensor sin reimprimir la tapa. Los transductores quedan a 26 mm bajo la cara inferior de la tapa y a **30 mm del surco
MAX** del embudo (el HC-SR04 no mide a menos de 2 cm). La capacidad hasta MAX es ≈ 632 cm³; los umbrales de alerta del
firmware son porcentajes de **volumen** (con el 20 % de la altura queda solo el 4,8 % del alimento): el generador
imprime a qué altura sobre la boca del embudo cae cada umbral.

### Estación solar remota (recomendación del profesor)

Estación solar

El panel ya no se atornilla a la torre: la estación se coloca donde haya sol y se une al cajón de energía con un cable
y un conector GX12. La bandeja gira sobre dos tornillos M4 que roscan en tuercas alojadas en sus nudillos (hexágono con
el vértice hacia arriba: se imprime sin puente) y se fija por fricción entre 0° y 75°; el generador verifica que en
todo ese rango no toque la base.

## Impresión en la Elegoo Neptune 4 Plus

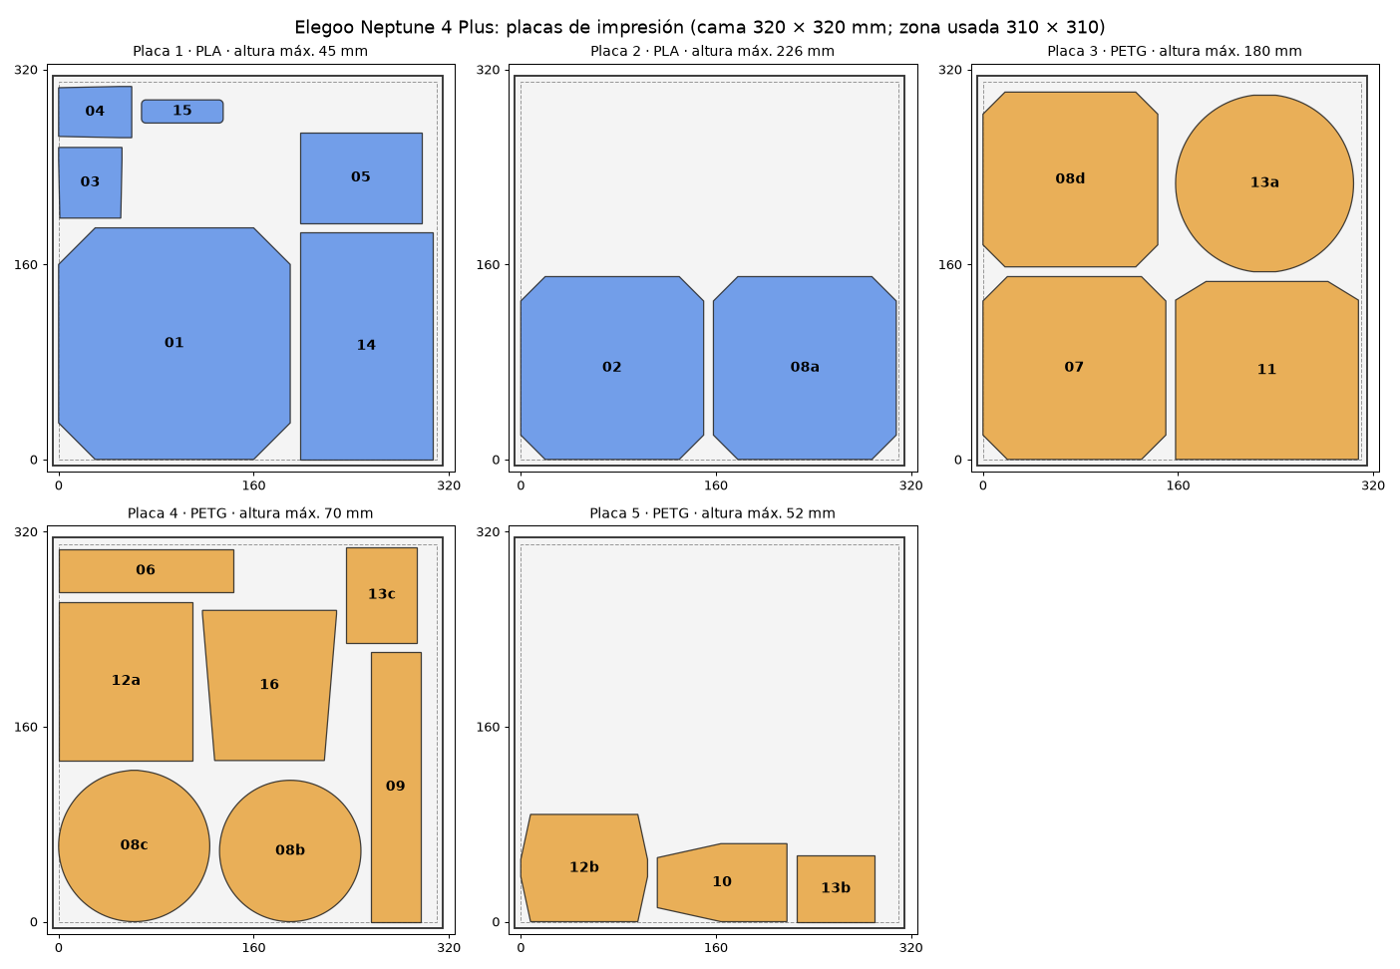
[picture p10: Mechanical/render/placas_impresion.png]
Placas de impresión


El [plan de impresión](plan_impresion.md) agrupa las piezas en **5 placas** por material y da el filamento y el tiempo
de cada pieza laminada con PrusaSlicer (perfil equivalente: boquilla 0,4, capa 0,2 mm). Total ≈ **1,0 kg de PLA +
1,25 kg de PETG**, ≈ 86 h de impresión.

| Parámetro | Valor recomendado |
|---|---|
| Laminador | Elegoo Cura u OrcaSlicer con el perfil **Elegoo Neptune 4 Plus**; importar los STL **sin rotarlos** |
| Material en contacto con alimento (07, 08b, 08c, 08d, 09, 10, 11) y tapa (13a, 13b, 13c) | **PETG** apto para contacto con alimentos (o PLA de color natural sin aditivos); boquilla de acero inoxidable si se busca aptitud alimentaria |
| Estación solar (12a, 12b) | **PETG o ASA** (sol y lluvia; el PLA se ablanda a ~55–60 °C al sol) |
| Viga del servo (06) y cajón de energía (16) | PETG (rigidez sostenida y calor de los convertidores) |
| Resto de la estructura (01, 02, 03, 04, 05, 08a, 14, 15) | PLA (o PETG) |
| Capa | 0,2 mm (0,16 mm en 08b y 08c para mejor acabado de la superficie de deslizamiento) |
| Perímetros | 3 (las paredes de 3 mm quedan macizas con boquilla de 0,4 mm) |
| Relleno | 20 % giroide; 40 % en 06, 08b, 12a, 12b y 16 |
| Temperaturas orientativas | PLA 210 °C / cama 60 °C; PETG 240 °C / cama 75 °C (use las de su filamento) |
| Soportes | **No hacen falta.** Puentes presentes: techo de la abertura del pico (42 mm), techo interior del conducto y del pico (36–37 mm), esquinas del anillo superior de la tolva (≤ 17 mm), brida del pico a 45°, orejetas internas de los pods (≤ 8 mm apoyadas en dos paredes), túnel de la brida en 12a (16 mm). El ala de la cápsula 13b y el avellanado de 13a están exactamente a 45° |
| Adherencia | La placa PEI de la Neptune 4 Plus agarra bien el PLA; para PETG use la cara texturizada o pegamento en barra (el PETG se pega demasiado a la PEI lisa). Borde (brim) de 5 mm en 02 y 07 si se despegan las esquinas |
| Tolerancias | Encaje entre módulos 0,3 mm por lado; ranuras de placas 1,8–2,0 mm; agujeros pasantes M3 Ø3,4; agujeros para rosca en plástico Ø2,5; M4 pasante Ø4,4; tuerca M4 en hexágono de 7,3 mm entre caras |
| Prueba previa | Imprimir primero 06, 15 y 13c (rápidas) y comprobar el MG995 y los tornillos antes de las piezas grandes |

**Higiene:** las superficies impresas tienen microsurcos entre capas. Lavar con agua tibia y jabón (no
lavavajillas: el PLA/PETG se deforma), secar bien antes de volver a cargar alimento. Para uso prolongado se
recomienda apoyar un cuenco de acero inoxidable sobre el comedero 11.

## Orden de montaje (resumen)

El detalle, con una imagen por paso, la tornillería exacta y las comprobaciones, está en el
[manual de armado](../Documentation/manual_armado/Manual_de_Armado.md).

1. **Cajón de energía (16)** con sus módulos (ajustar Buck A = 6,0 V y Buck B = 5,0 V **antes**) y el GX12 → deslizar
   en la base (01).
2. **Cuerpo (02):** bandeja 05 y cápsulas 03/04 **antes** de unirlo a la base (4 × M3×12 desde arriba).
3. **Conducto (09)** desde arriba y **pico (10)** desde fuera.
4. **Servo:** centrarlo con `SERVO 1500`, atornillarlo a la viga 06 y apoyarla en las ménsulas.
5. **08a** sobre el labio de 02 y **08d** dentro de 08a.
6. **Disco 08b** en la marca CERRADO; **calibrar** las posiciones con las marcas a la vista.
7. **08c** con la chaveta en su chavetero.
8. **Tolva 07** (boca en el zócalo de 08c, tubo de cables atrás a la izquierda).
9. **Tapa 13a + cápsula 13b con el HC-SR04 n.º 2 + 13c**; cable por la ranura y el tubo de la esquina hasta J5;
   calibrar `NIVEL VACIO` / `NIVEL LLENO`.
10. **Tapa de servicio 14** y **comedero 11**.
11. **Estación solar 12a + 12b** con el panel, al sol; enchufar el GX12 con S1 apagado.

## Otras vistas

| Atrás | Explosionada | Corte |
|---|---|---|
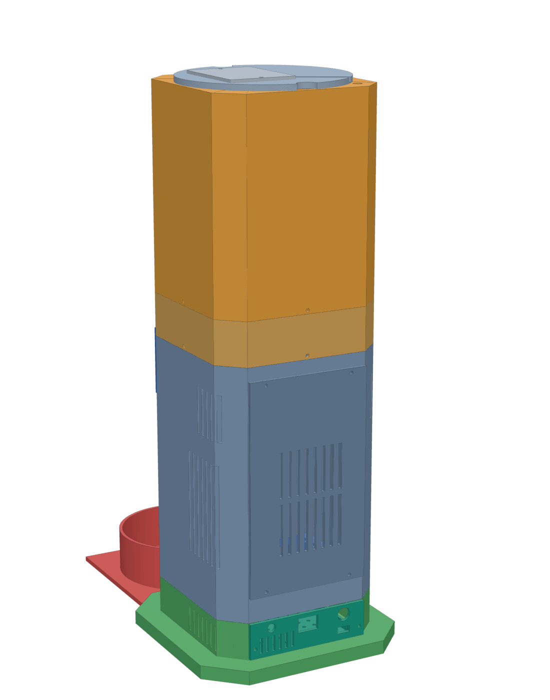
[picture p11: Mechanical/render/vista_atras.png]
Atrás
|  | Explosionada | Corte 3D |

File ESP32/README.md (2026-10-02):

# ESP32 DevKit V1 — Controlador del dispensador

Controla todo el sistema: lee el HC-SR04 de presencia, pide la clasificación al PC, **decide**
si dispensa y mueve el MG995. Además vigila el **nivel de alimento de la tolva** con un segundo HC-SR04 y avisa al PC
cuando se está acabando. Implementa la máquina de estados con manejo de errores.

## Archivos

| Archivo | Responsabilidad |
|---|---|
| `Dispensador_ESP32/Dispensador_ESP32.ino` | `setup()`/`loop()`, une los módulos, `/status`, comandos serie |
| `Dispensador_ESP32/config.h` | Pines, red, umbrales, tiempos, dosis (valores PROVISIONALES marcados) |
| `Dispensador_ESP32/Controlador.*` | Máquina de estados (sin dependencias de hardware: se prueba en PC) |
| `Dispensador_ESP32/Ultrasonico.*` | HC-SR04 con mediana de N disparos |
| `Dispensador_ESP32/Dosificador.*` | PWM del MG995 con rampa, ciclos llenar/descargar, anti-atasco |
| `Dispensador_ESP32/Energia.*` | Tensiones de batería, riel del servo y panel (ADC1) |
| `Dispensador_ESP32/NivelTolva.*` | HC-SR04 n.º 2 (GPIO19/21): distancia, calibración VACIO/LLENO en la flash (NVS), % de volumen |
| `Dispensador_ESP32/NivelGeometria.h` | Tabla altura → volumen de la tolva (la calcula y verifica `Mechanical/generar_stl.py`) |
| `Dispensador_ESP32/Red.*` | Wi-Fi, cliente HTTP (PC y cámara), servidor `/status`, `POST /alerta` |
| `Dispensador_ESP32/secrets_ejemplo.h` | Plantilla de credenciales Wi-Fi |
| `test_host/` | Pruebas de la máquina de estados y verificación de compilación en PC |

## Compilar y cargar

1. Copiar `Dispensador_ESP32/secrets_ejemplo.h` como `Dispensador_ESP32/secrets.h` y completar SSID/clave (red **2,4 GHz**).
2. Revisar `config.h`: IP del ESP32, del PC (`URL_PC`) y de la cámara (`URL_CAMARA`).
3. **Arduino IDE**: abrir `Dispensador_ESP32/Dispensador_ESP32.ino`, placa *DOIT ESP32 DEVKIT V1*, instalar la biblioteca **ArduinoJson 7** (Gestor de bibliotecas). Compatible con el núcleo esp32 2.x y 3.x.
   **PlatformIO**: `pio run -t upload && pio device monitor` desde esta carpeta.
4. Si la placa se alimenta desde el bus de 5 V **y** se conecta el USB al PC, verificar que la placa tenga diodo entre VBUS y VIN; si no se sabe, desconectar el 5 V externo mientras se programa.

## Comandos del monitor serie (115200 baudios)

| Comando | Uso |
|---|---|
| `DIST` | Distancia actual del HC-SR04 de presencia |
| `NIVEL` | Nivel de la tolva: % del volumen, % de altura y distancia |
| `NIVEL VACIO` | Calibra con la tolva **vacía** (tapa puesta); se guarda en la flash |
| `NIVEL LLENO` | Calibra con el alimento nivelado en el **surco MAX**; se guarda en la flash |
| `SERVO <us>` | Mueve el disco a un pulso (500–2500 µs) — calibración de posiciones |
| `CICLO <n>` | Ejecuta n ciclos de dosis (para pesar con balanza) |
| `CLASIFICAR` | Pide una clasificación al PC **sin dispensar** |
| `ENERGIA` | Tensiones de batería, riel del servo y panel |
| `ESTADO` | JSON de estado (incluye `nivel_tolva`, `alerta_tolva` y `alerta_pendiente`) |
| `RESET` | Borra ERROR_SERVO / ERROR_MECANISMO (también: botón BOOT 2 s) |

No existe un comando remoto de "dar comida": dispensar manualmente exige acceso físico al USB.

## Fotos cada 2 s (idea del profesor)

Cuando el HC-SR04 confirma a la mascota, el ESP32 pide una clasificación (= una foto nueva). Si el PC responde 0 y la
mascota sigue delante, pide otra a los `REINTENTO_CLASIFICACION_MS` (2 s), como máximo `MAX_INTENTOS_CLASIFICACION`
(5) fotos por visita. El `/status` de la cámara se consulta solo antes de la primera foto; en las siguientes, si la
cámara falla, el PC responde 502 y el ESP32 pasa a ERROR_CAMARA igual.

## Sensor de nivel y alertas

Cada 60 s (y después de cada ración), en el estado ESPERANDO, se mide el nivel. Con 3 lecturas seguidas:
< `NIVEL_ALERTA_PCT` (20 % del volumen) → `COMIDA_BAJA`; ≤ `NIVEL_VACIO_PCT` (3 %) → `COMIDA_AGOTADA` (no se dispensa);
> `NIVEL_REARME_PCT` (30 %) → `COMIDA_REPUESTA`. Cada alerta se envía con `POST URL_PC/alerta`
(`{"tipo":"COMIDA_BAJA","nivel":18}`) y se reenvía cada 30 s hasta que el PC responde 200. Si el sensor no tiene eco
se avisa una vez (`SENSOR_NIVEL_SIN_LECTURA`) y **no se bloquea** la alimentación. Parámetros en la sección 8 de
`config.h` (`USAR_SENSOR_NIVEL 0` lo desactiva).

## Verificación sin hardware

Todo esto corre automáticamente en GitHub Actions (`.github/workflows/verificacion.yml`) en cada `push`.

### 1. Lógica en el PC (segundos)

```bash
cd ESP32/test_host
make                       # 26 escenarios de la máquina de estados (5 del sensor de nivel, 2 de las fotos cada 2 s)
git clone --depth 1 https://github.com/bblanchon/ArduinoJson
make sintaxis              # compila todo el firmware (ESP32 y ESP32-CAM) contra stubs de Arduino, API núcleo 2.x y 3.x
```

### 2. Compilación real con la cadena de Espressif

```bash
URL=https://espressif.github.io/arduino-esp32/package_esp32_index.json
arduino-cli core install esp32:esp32@3.0.7 --additional-urls $URL     # o 2.0.17
arduino-cli lib install "ArduinoJson@7.4.2"
arduino-cli compile --fqbn esp32:esp32:esp32doit-devkit-v1 --warnings all ESP32/Dispensador_ESP32
arduino-cli compile --fqbn "esp32:esp32:esp32cam:PartitionScheme=huge_app" --warnings all ESP32_CAM/Camara_ESP32CAM
```

| Núcleo | ESP32 (flash / RAM estática) | ESP32-CAM (flash / RAM estática) |
|---|---|---|
| 2.0.17 | 960 kB (73 %) / 48 kB | 847 kB (26 %) / 50 kB |
| 3.0.7 | 1 097 kB (83 %) / 48 kB | 1 023 kB (32 %) / 50 kB |

La única advertencia es la intencional de `secrets.h` cuando todavía no se creó.

### 3. Firmware real en el emulador QEMU de Espressif

QEMU emula el ESP32 (CPU, memoria flash, temporizadores, GPIO, PWM) pero **no la radio Wi-Fi ni el ADC**. La
variante `-DSIMULACION_QEMU` reemplaza solo esas dos partes (Wi-Fi "desconectado", tensiones nominales); todo lo
demás es el código real. En `setup()` ejecuta una autoprueba (AYUDA, ESTADO, DIST, ENERGIA, SERVO, CICLO,
CLASIFICAR, NIVEL, RESET) que `qemu_autoprueba.sh` verifica:

```bash
arduino-cli compile --fqbn esp32:esp32:esp32doit-devkit-v1 --build-path build/qemu \
  --build-property "compiler.cpp.extra_flags=-DSIMULACION_QEMU" ESP32/Dispensador_ESP32
# QEMU: https://github.com/espressif/qemu/releases (paquete qemu-xtensa-softmmu, Linux; requiere libslirp0)
ESP32/test_host/qemu_autoprueba.sh build/qemu \
  ~/.arduino15/packages/esp32/hardware/esp32/2.0.17/tools/partitions/boot_app0.bin qemu/bin/qemu-system-xtensa
```

Resultado: `AUTOPRUEBA QEMU: OK` (14 comprobaciones; un ciclo de dosis completo tarda 3,8 s). Esta prueba
detectó y permitió corregir un error real: con el botón BOOT mantenido (o GPIO0 a nivel bajo) los errores se
borraban cada 50 ms; ahora cada pulsación larga produce un solo borrado.

**Nunca** compilar con `SIMULACION_QEMU` para la placa real: desactiva el Wi-Fi y las mediciones.

Lo que ninguna de estas pruebas sustituye: Wi-Fi, cámara, HC-SR04, servo y tensiones reales (plan de pruebas del
README principal, §38).

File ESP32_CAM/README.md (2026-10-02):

# ESP32-CAM (AI-Thinker) — Captura de imágenes

Responsabilidad única: **capturar y entregar un JPEG** cuando el PC lo pide. No
clasifica y no controla el servo.

| Endpoint | Respuesta |
|---|---|
| `GET /capture` | `200 image/jpeg` (foto nueva, VGA 640×480) · `503` si la cámara falla |

**Modo foto, no video (idea del profesor):** la cámara se configura con un solo búfer y `CAMERA_GRAB_WHEN_EMPTY`, así
el controlador no captura cuadros de forma continua: toma uno cada vez que el PC pide `/capture` (solo cuando el
HC-SR04 detectó a una mascota, una foto cada ~2 s mientras siga delante). El sensor queda encendido para que la
exposición automática esté siempre ajustada, y el cuadro viejo que pudo quedar en el búfer se descarta: cada respuesta
es una foto **actual**.
| `GET /status` | `200 application/json` `{"camara":true,"psram":true,"fotos_ok":..,"rssi":..}` |

## Programación (no tiene USB propio)

* Opción A: placa **ESP32-CAM-MB** (USB) — conectar y cargar.
* Opción B: adaptador **USB-TTL a 3,3 V lógicos**:

| USB-TTL | ESP32-CAM |
|---|---|
| 5V | 5V |
| GND | GND |
| TX | U0R (GPIO3) |
| RX | U0T (GPIO1) |
| — | **GPIO0 → GND** solo mientras se carga; luego quitar el puente y pulsar RST |

Arduino IDE: placa **AI Thinker ESP32-CAM**, *PSRAM: Enabled*, *Partition: Huge APP*.
Copiar `Camara_ESP32CAM/secrets_ejemplo.h` como `secrets.h` y revisar `config.h` (IP fija `192.168.1.51`).

## Avisos

* Los GPIO 0, 5, 18, 19, 21–23, 25–27, 32, 34–36, 39 están ocupados por la cámara; 4 = flash; 33 = LED rojo; 16 = PSRAM. **No se cablea ningún GPIO** al ESP32: la comunicación es por Wi-Fi.
* Alimentar por el pin **5V** con una fuente estable (≥1 A disponible) y 470 µF + 100 nF junto al módulo. Con fuentes débiles aparecen reinicios por *brownout*: **no desactivar** el detector de brownout, corregir la alimentación.
* El flash (GPIO4) viene desactivado (`USAR_FLASH 0`): es muy brillante y puede asustar a la mascota.

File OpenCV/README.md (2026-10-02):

# Servidor de visión (PC / notebook) — Python + OpenCV

| Pieza | Qué hace |
|---|---|
| ESP32-CAM | Solo captura el JPEG |
| `servidor_vision.py` | Servidor HTTP (biblioteca estándar). Recibe `GET /classify` del ESP32, pide fotos a la cámara y responde; recibe las alertas de nivel (`POST /alerta`) y sirve el **panel web** (`GET /`) |
| `alertas.py` | Guarda las alertas de la tolva y, si se configura, las reenvía al celular con **ntfy** |
| OpenCV | Decodifica el JPEG, mide brillo y nitidez (varianza del Laplaciano), aplica CLAHE, prepara el *blob* y **ejecuta la red con `cv2.dnn`** |
| Modelo MobileNetV2 (ImageNet) | Interpreta la imagen. P(perro) = suma de las 118 razas (índices 151–268); P(gato) = suma de 5 gatos domésticos (281–285) |
| Regla de decisión | 1 = PERRO, 2 = GATO, 0 = INDETERMINADO (no dispensar) |
| Fotos de la visita | Cada pedido es **una** foto; si la mascota sigue delante sin identificarse, el ESP32 pide otra cada ~2 s. Las fotos de la misma visita en las que se ve un animal (últimos 5 s, máx. 3) se promedian (`combinar_visita`) |

## Instalación y uso

```bash
cd OpenCV
python -m venv .venv && source .venv/bin/activate      # Windows: .venv\Scripts\activate
pip install -r requirements.txt
python descargar_modelo.py                              # una sola vez (14 MB, verifica SHA-256)
python servidor_vision.py --camara http://192.168.1.51 --esp32 http://192.168.1.52 --puerto 8000
```

Permitir el puerto 8000 en el firewall del PC (Windows lo pregunta la primera vez).

## Panel web y alertas de comida (sensor de nivel de la tolva)

* **Panel web:** abra `http://IP-DEL-PC:8000/` en el navegador (también desde el celular, en la misma red). Muestra la
  barra de nivel de la tolva, el estado del ESP32 (lo lee de su `/status`), las últimas alertas y las últimas
  clasificaciones; se actualiza cada 5 s. Los mismos datos en JSON: `GET /panel.json`.
* **Alertas:** el ESP32 envía `POST /alerta` con `{"tipo": ..., "nivel": ...}`:

  | Tipo | Cuándo | Mensaje |
  |---|---|---|
  | `COMIDA_BAJA` | queda < 20 % del volumen | «La comida del dispensador se está acabando (nivel ~18 %). Recargue la tolva.» |
  | `COMIDA_AGOTADA` | ≤ 3 % | «La tolva está vacía: el dispensador no entregará raciones hasta recargarla.» |
  | `COMIDA_REPUESTA` | > 30 % después de una alerta | «Tolva recargada (nivel ~64 %).» |
  | `SENSOR_NIVEL_SIN_LECTURA` | el sensor no da eco | «El sensor de nivel de la tolva no responde: revise el cable de la tapa.» |

* **Al celular (opcional, gratis, sin cuentas):** instale la app **ntfy** (Android/iOS), suscríbase a un tema con un
  nombre difícil de adivinar (por ejemplo `dispensador-ana-7f3k9`) y arranque el servidor con `--ntfy dispensador-ana-7f3k9`
  (o `NTFY_TOPICO` en `config.py`). El PC necesita Internet; si no lo tiene, el panel web sigue funcionando y el
  dispensador no se entera (el envío va en segundo plano). Cualquiera que conozca el nombre del tema puede leer los
  avisos: no ponga datos personales en él.
* Probar sin el ESP32: `curl -X POST http://127.0.0.1:8000/alerta -d '{"tipo":"COMIDA_BAJA","nivel":18}'`.

## Probar sin hardware

```bash
python -m unittest discover -s tests -v                   # 29 pruebas (sin cámara ni modelo; visitas, alertas, panel)
python simulador_camara.py --imagenes carpeta_fotos --puerto 8081 &
python servidor_vision.py --camara http://127.0.0.1:8081
curl "http://127.0.0.1:8000/classify?dist=25"
```

## ¿Wi-Fi o local? Medir los tiempos de la red

Todo el análisis es **local**: la foto va de la ESP32-CAM al PC por la red local y no pasa por Internet (README
principal, §13.5). Para medir los tiempos reales de su red (con el hardware encendido y el servidor en marcha):

```bash
python medir_red.py --clasificar         # ESP32 /status, cámara /status y /capture, análisis y /classify completo
```

La última foto analizada se ve en el panel web y en `http://IP-DEL-PC:8000/ultima.jpg`.

## Calibrar umbrales con fotos reales de la cámara instalada

```bash
python capturar_dataset.py --clase perro --cantidad 30
python capturar_dataset.py --clase gato  --cantidad 30
python capturar_dataset.py --clase otros --cantidad 30     # personas, juguetes, fondo vacío
python probar_imagenes.py dataset --barrido               # matriz de confusión y umbral sugerido
```

Ajustar `UMBRAL_CONFIANZA`, `MARGEN_MINIMO`, `BRILLO_*` y `NITIDEZ_MIN` en `config.py`
(o con variables de entorno `DISPENSADOR_*`).

## Limitaciones honestas

* El modelo reconoce **perro o gato en general**, no a una mascota concreta.
* Una foto de un perro en un celular o un peluche realista puede clasificarse como perro.
* Zorros, lobos o felinos grandes pueden dar probabilidades altas en clases cercanas; los umbrales y el margen reducen el riesgo, no lo eliminan.
* Mejora futura: reentrenar (transfer learning) con fotos propias de las mascotas de la casa.

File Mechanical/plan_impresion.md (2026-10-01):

# Plan de impresión · Elegoo Neptune 4 Plus

Generado por `plan_impresion.py` (no editar a mano). Volumen de la impresora: 320 × 320 × 385 mm; todas las piezas se verificaron con un margen de 5 mm por lado (`generar_stl.py`).

Placas

Importe en el laminador (Elegoo Cura u OrcaSlicer con el perfil «Elegoo Neptune 4 Plus») los STL de cada placa **sin rotarlos** (ya vienen orientados) y use *Organizar*. Si prefiere menos riesgo, imprima las piezas altas (02, 07) solas: un fallo no arruina las demás.

## Placa 1 · PLA · ≈368 g · ≈15 h 55 min

| Pieza | Huella × altura (mm) | Relleno | Filamento | Tiempo (orientativo) |
|---|---|---|---|---|
| 01_Base_Torre | 190 × 190 × 45 | 20% | 219 g (73.4 m) | 9 h 25 min |
| 14_Tapa_Lateral_Servicio | 109 × 186 × 6 | 20% | 57 g (19.1 m) | 2 h 17 min |
| 05_Modulo_ESP32 | 100 × 74 × 29 | 20% | 44 g (14.7 m) | 1 h 46 min |
| 03_Modulo_HC_SR04 | 52 × 58 × 28 | 20% | 22 g (7.5 m) | 0 h 59 min |
| 04_Modulo_ESP32_CAM | 42 × 60 × 34 | 20% | 23 g (7.7 m) | 1 h 14 min |
| 15_Separadores | 67 × 19 × 10 | 20% | 3 g (1.0 m) | 0 h 16 min |

## Placa 2 · PLA · ≈615 g · ≈22 h 53 min

| Pieza | Huella × altura (mm) | Relleno | Filamento | Tiempo (orientativo) |
|---|---|---|---|---|
| 02_Cuerpo_Principal | 150 × 150 × 226 | 20% | 532 g (178.2 m) | 20 h 04 min |
| 08a_Carcasa_Dosificador | 150 × 150 × 44 | 20% | 83 g (27.8 m) | 2 h 49 min |

## Placa 3 · PETG · ≈794 g · ≈27 h 08 min

| Pieza | Huella × altura (mm) | Relleno | Filamento | Tiempo (orientativo) |
|---|---|---|---|---|
| 07_Tolva | 150 × 150 × 180 | 20% | 533 g (174.5 m) | 17 h 26 min |
| 11_Comedero | 150 × 146 × 44 | 20% | 116 g (37.9 m) | 4 h 06 min |
| 13a_Tapa_Superior_Tolva | 146 × 145 × 13 | 20% | 56 g (18.4 m) | 2 h 10 min |
| 08d_Placa_Base_Dosificador | 143 × 143 × 32 | 20% | 89 g (29.2 m) | 3 h 26 min |

## Placa 4 · PETG · ≈384 g · ≈17 h 13 min

| Pieza | Huella × altura (mm) | Relleno | Filamento | Tiempo (orientativo) |
|---|---|---|---|---|
| 08c_Placa_Superior_Dosificador | 124 × 124 × 14 | 20% | 44 g (14.3 m) | 1 h 44 min |
| 12a_Estacion_Solar_Base | 130 × 110 × 70 | 40% | 82 g (26.8 m) | 3 h 56 min |
| 16_Soporte_Estructural_Cajon_Energia | 110 × 123 × 31 | 40% | 47 g (15.2 m) | 2 h 26 min |
| 08b_Disco_Dosificador | 116 × 116 × 14 | 40% | 87 g (28.6 m) | 4 h 52 min |
| 09_Conducto_Alimento | 41 × 221 × 50 | 20% | 94 g (30.9 m) | 2 h 55 min |
| 06_Soporte_MG995 | 143 × 35 × 5 | 40% | 18 g (5.9 m) | 0 h 53 min |
| 13c_Tapa_Capsula_Sensor | 58 × 78 × 2 | 20% | 12 g (3.8 m) | 0 h 26 min |

## Placa 5 · PETG · ≈77 g · ≈3 h 08 min

| Pieza | Huella × altura (mm) | Relleno | Filamento | Tiempo (orientativo) |
|---|---|---|---|---|
| 12b_Estacion_Solar_Bandeja | 104 × 88 × 14 | 40% | 21 g (6.9 m) | 0 h 56 min |
| 10_Salida_Alimento | 64 × 106 × 52 | 20% | 33 g (10.7 m) | 1 h 19 min |
| 13b_Capsula_Sensor_Nivel | 54 × 64 × 31 | 20% | 23 g (7.5 m) | 0 h 53 min |

## Totales

| Material | Filamento | Bobinas de 1 kg |
|---|---|---|
| PLA | ≈983 g | 2 (con 15 % de reserva para pruebas y fallos) |
| PETG | ≈1255 g | 2 (con 15 % de reserva para pruebas y fallos) |

Tiempo total orientativo: **≈86 h 17 min** de impresión (suma de las piezas).

## Perfil usado para estimar (equivalente a la Neptune 4 Plus)

| Ajuste | PLA | PETG |
|---|---|---|
| Boquilla / capa / primera capa | 0,4 / 0,2 / 0,2 mm | 0,4 / 0,2 / 0,2 mm |
| Temperatura boquilla / cama | 210 / 60 °C | 240 / 75 °C |
| Perímetros / capas sup. / inf. | 3 / 5 / 4 | 3 / 5 / 4 |
| Relleno | giroide 20 % (40 % en 06, 08b, 12a, 12b, 16) | ídem |
| Flujo volumétrico máx. | 18 mm³/s | 12 mm³/s |
| Velocidades (perímetro ext. / int. / relleno) | 80 / 120 / 200 mm/s | ídem (las limita el flujo) |
| Soportes | **ninguno** (diseño sin voladizos > 45°) | ídem |
| Adherencia | falda; borde (brim) de 5 mm solo en 02 y 07 si la cama no agarra bien | ídem; en PETG use pegamento en barra o la cara texturizada de la placa PEI |

Los tiempos los calcula PrusaSlicer con estas velocidades; su laminador puede dar otros valores. Los gramos dependen poco del laminador.

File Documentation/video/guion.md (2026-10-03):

# Guion del video · Dispensador inteligente

Texto de la narración, escena por escena (el mismo de los subtítulos). Sirve para leerlo en voz alta en la
presentación o para grabar la narración con su propia voz.

### Dispensador inteligente de alimento para mascotas · 0:00

Este es el dispensador inteligente de alimento para mascotas. Funciona con IoT, visión artificial y energía solar. En este video vemos cómo funciona y cómo se arma, paso a paso.

### ¿Qué hace? · 0:14

Cuando un perro o un gato se acerca, el dispensador lo detecta y le saca una foto. Reconoce si es perro o gato, y le entrega la ración que le corresponde. Si no está seguro, no entrega nada.

### Componentes · 0:28

Los componentes principales son: el ESP32, que es el cerebro; la ESP32-CAM, que saca las fotos; dos sensores ultrasónicos HC-SR04, uno para detectar a la mascota y otro para medir la comida; el servomotor MG995, que mueve el dosificador; y un panel solar. Además lleva una batería de litio con su protección, y convertidores de 6 V para el servo y de 5 V para la electrónica.

### Cómo funciona · 0:59

El funcionamiento es así. Uno: el sensor ultrasónico detecta que algo se acercó a menos de 35 cm. Dos: el ESP32 le pide al computador que identifique a la mascota. Tres: el computador le pide una foto a la cámara y la analiza con OpenCV y una red neuronal, MobileNetV2. Cuatro: responde 1 si es perro, 2 si es gato, o 0 si no está seguro. Cinco: el ESP32 revisa las reglas, como el tiempo mínimo entre raciones y el límite diario, y recién ahí mueve el servo.

### Fotos, no video · 1:35

La cámara no graba video. Saca una foto solo cuando llega la mascota. Si con esa foto no alcanza, saca otra cada 2 s, hasta cinco fotos. El computador combina las fotos de la misma visita: así una foto movida no provoca un error.

### Todo en una red local · 1:53

Todo funciona en una red local. Los tres equipos se comunican por wifi dentro de la misma sala, y no se usa Internet. Por eso es rápido: el análisis de cada foto tarda unos 20 ms en el computador. Para la feria se puede usar el punto de acceso del celular, con los datos móviles apagados.

### El dosificador · 2:13

El alimento se dosifica con un disco que tiene un hueco. El servo lleva el hueco debajo de la tolva, se llena, gira 100° y lo vacía sobre el conducto. Nunca conecta la tolva con el conducto al mismo tiempo, así que no cae comida de más. Cada vuelta entrega siempre el mismo volumen, y los gramos se calibran con una balanza.

### Recorrido del alimento · 2:36

El alimento baja por un conducto cerrado, al frente de la torre. La electrónica queda atrás, separada por un tabique: ningún cable pasa por donde pasa la comida.

### Sensor de nivel en la tolva · 2:47

En la tapa hay un segundo sensor ultrasónico, que mide cuánta comida queda. Como la tolva es un embudo, el porcentaje se calcula por volumen y no por altura. Cuando queda menos del 20 %, el ESP32 envía una alerta al computador y al celular, con la aplicación ntfy. Si la tolva se vacía, deja de dar raciones hasta que se recargue.

### Panel web en el computador · 3:11

En el computador hay un panel web, que se abre desde el navegador o desde el celular. Muestra el nivel de la tolva, el estado del ESP32, las alertas y la última foto analizada.

### Energía · 3:24

La energía viene de dos baterías de litio en serie, protegidas por un BMS y un fusible. Un convertidor da 6 V solo para el servo, y otro da 5 V para la electrónica. El panel aporta 0,3 W, y el sistema consume en promedio 1,75 W: por eso la carga principal es por USB-C, y el panel es demostrativo.

### Estación solar remota · 3:49

El panel va aparte, en una estación que se ubica donde haya sol, y se conecta a la torre con un cable y un conector GX12. La bandeja se inclina según el lugar, y se fija con dos tornillos.

### Esquema eléctrico completo · 4:03

Este es el esquema eléctrico completo. El servo recibe sus 6 V directo del convertidor; del ESP32 solo recibe la señal. Las señales de eco de los dos sensores pasan por divisores de resistencias, para no dañar el ESP32.

### Placa de control · 4:20

La placa de control se suelda siguiendo una lista de 34 cables numerados, y un programa verifica que coincida con el código.

### Impresión 3D · Elegoo Neptune 4 Plus · 4:29

Todas las piezas se imprimen en la Elegoo Neptune 4 Plus, sin soportes, en cinco placas. Las que tocan el alimento van en PETG, y el resto en PLA: son unos 2,2 kg de filamento.

### Armado paso a paso · 4:43

Ahora, el armado paso a paso.

### Paso 1 de 11 · Base y cajón de energía · 4:46

Paso uno. Se arma el cajón de energía y se desliza dentro de la base, desde atrás.

### Paso 2 de 11 · Cuerpo, bandeja y cápsulas · 4:53

Paso dos. En el cuerpo se atornillan la bandeja del ESP32 y las cápsulas del sensor y de la cámara. Después el cuerpo se atornilla sobre la base.

### Paso 3 de 11 · Conducto y pico · 5:04

Paso tres. El conducto de alimento se baja desde arriba, y el pico de salida se coloca desde afuera.

### Paso 4 de 11 · Servo y viga · 5:11

Paso cuatro. Con el servo centrado en 1500 µs, se atornilla a su viga, que se apoya dentro del cuerpo.

### Paso 5 de 11 · Carcasa y placa base · 5:19

Paso cinco. Se colocan la carcasa del dosificador y la placa base, con la salida hacia el frente.

### Paso 6 de 11 · Disco dosificador · 5:27

Paso seis. El disco se atornilla al servo en la marca de cerrado, y se calibran las posiciones.

### Paso 7 de 11 · Placa superior · 5:33

Paso siete. La placa superior se asienta con su chaveta, sin tornillos.

### Paso 8 de 11 · Tolva · 5:39

Paso ocho. La tolva va encima, con la boca del embudo en su lugar.

### Paso 9 de 11 · Tapa con el sensor de nivel · 5:45

Paso nueve. En la tapa va la cápsula con el sensor de nivel. Su cable baja por un conducto oculto en una esquina.

### Paso 10 de 11 · Tapa trasera y comedero · 5:53

Paso diez. Se cierra la tapa trasera de la electrónica y se encaja el comedero.

### Paso 11 de 11 · Estación solar · 6:00

Paso once. La estación solar se arma aparte: el panel va en la bandeja, que se inclina y se fija con dos tornillos.

### Calibración y pruebas · 6:08

Antes de usarlo se calibran las posiciones del disco, los gramos por ciclo, la distancia de detección, los umbrales de la cámara y el sensor de nivel. Y todo el proyecto se prueba automáticamente en cada cambio: la lógica, la visión, la compilación del firmware y la geometría de las piezas.

### Dispensador inteligente · 6:27

Así, el dispensador reconoce a cada mascota, le da su ración, avisa cuando falta comida y funciona de manera local. El código, los archivos para imprimir y el manual de armado están en el repositorio del proyecto.

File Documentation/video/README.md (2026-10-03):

# Video: funcionamiento y armado

**[Dispensador_IoT_funcionamiento_y_armado.mp4](Dispensador_IoT_funcionamiento_y_armado.mp4)** · 1280 × 720 · ≈ 7 min ·
narración en español con subtítulos incrustados ([subtítulos aparte en .srt](Dispensador_IoT_funcionamiento_y_armado.srt)).

| Parte | Contenido |
|---|---|
| Qué es | Torre girando; qué hace; componentes |
| Funcionamiento | Los 5 pasos (detecta → pregunta → foto y análisis → responde → decide y entrega); fotos cada 2 s en vez de video; red local sin Internet |
| Dosificador | Animación en corte: el disco lleva una croqueta de la tolva al conducto y de ahí al comedero |
| Seguridad del alimento | Recorrido cerrado separado de la electrónica |
| Sensor de nivel | Porcentaje por volumen, alertas al computador y al celular, panel web |
| Energía | Batería 2S, convertidores de 6 V y 5 V, estación solar remota (animada) |
| Electrónica | Recorrido por el esquema completo; placa de control |
| Impresión | 5 placas para la Elegoo Neptune 4 Plus |
| Armado | Los 11 pasos animados (las piezas nuevas entran a su lugar) |
| Cierre | Calibración, pruebas automáticas y repositorio |

El texto completo de la narración está en [guion.md](guion.md): sirve para leerlo en la presentación o para grabar el
video con su propia voz.

## Cómo se generó (y cómo volver a generarlo)

Todo sale del mismo modelo y la misma documentación del repositorio; si se cambia una pieza o un texto, el video se
vuelve a armar con los mismos pasos. Fuentes en [`fuente/`](fuente):

| Archivo | Qué hace |
|---|---|
| `guion.py` | Escenas, textos en pantalla y narración (con la pronunciación de las siglas para la voz) |
| `hacer_audio.py` | Narración con voz neuronal sin conexión (Piper, voz `es_MX-claude-high`, vía `sherpa-onnx`) y tiempos de cada frase |
| `exportar_mallas.py` | Piezas en posición de ensamblaje (desde `Mechanical/generar_stl.py`) |
| `web/escena3d.html` + `render3d.mjs` | Animaciones 3D (three.js) renderizadas cuadro a cuadro con Chromium |
| `web/laminas.html` + `laminas.py` + `render_laminas.mjs` | Láminas explicativas |
| `hacer_video.py` | Une todo con ffmpeg: zoom suave en las láminas, paneo por el esquema, subtítulos y audio normalizado |

```bash
cd Documentation/video/fuente
pip install sherpa-onnx numpy trimesh manifold3d pillow
npm install three playwright              # o enlazar un node_modules que los tenga
# voz: https://github.com/k2-fsa/sherpa-onnx/releases/download/tts-models/vits-piper-es_MX-claude-high.tar.bz2
VOZ_DIR=ruta/vits-piper-es_MX-claude-high python hacer_audio.py salida
python exportar_mallas.py web/mallas
python escenas3d.py salida/tiempos.json salida/escenas3d.json
python -m http.server 8099 -d web &       # las páginas se sirven por HTTP
node render3d.mjs salida/escenas3d.json salida/cuadros 25
python laminas.py && node render_laminas.mjs salida/laminas
python hacer_video.py salida ../Dispensador_IoT_funcionamiento_y_armado.mp4
python guion_md.py salida/tiempos.json
```

La captura del panel web (`web/img/panel_web.png`) se tomó del servidor real con datos de demostración; la foto de
prueba que muestra el panel se reemplazó por un recuadro, porque era una imagen de terceros.

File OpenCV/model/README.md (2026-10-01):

# Modelo

Esta carpeta guarda el modelo y las etiquetas. **No se suben a GitHub** (14 MB);
se descargan y verifican (SHA-256) con:

```bash
cd OpenCV
python descargar_modelo.py
```

| Archivo | Origen | Licencia |
|---|---|---|
| `mobilenetv2-12.onnx` | ONNX Model Zoo – MobileNetV2 (ImageNet-1k) | Apache-2.0 |
| `imagenet_classes.txt` | Lista de 1000 clases ImageNet (repositorio `pytorch/hub`) | BSD |

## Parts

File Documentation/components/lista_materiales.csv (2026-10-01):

categoria | componente | cantidad | especificacion | uso | notas
principal | ESP32 DevKit V1 | 1 | ESP32-WROOM-32 30 pines (DOIT) | Controlador y actuador | Verificar si tiene diodo entre USB y VIN
principal | ESP32-CAM | 1 | AI-Thinker con OV2640 y PSRAM | Captura de imagenes
principal | HC-SR04 | 2 | Version de 5 V | Deteccion de aproximacion (1) y nivel de alimento en la tolva (1) | Recomendacion del profesor: el segundo va en la tapa (capsula 13b). Si es HC-SR04P puede ir a 3.3 V sin divisor
principal | Servomotor MG995 | 1 | Version 180 grados (NO la de giro continuo) | Dosificador | Incluye horns y tornillos
principal | Panel solar | 1 | ~3 V 100 mA | Captacion solar demostrativa en la estacion remota (12a + 12b) | Medir Voc Isc y dimensiones (PANEL_W PANEL_H en generar_stl.py)
programacion | ESP32-CAM-MB o adaptador USB-TTL 3.3 V | 1 |  | Cargar el firmware de la ESP32-CAM
auxiliar_energia | Celda Li-ion 18650 | 2 | Marca reconocida y capacidad real | Almacenamiento | 4 unidades para 2S2P (recomendado)
auxiliar_energia | Portapilas 2x18650 en serie | 1 |  | Montaje de las celdas | 2 si se usa 2S2P
auxiliar_energia | BMS 2S con balanceo | 1 | >= 5 A continuos; puerto comun | Proteccion de la bateria
auxiliar_energia | Cargador elevador USB-C 2S | 1 | Entrada 5 V; salida CC/CV 8.4 V | Carga principal | Verificar que este configurado para 2 celdas
auxiliar_energia | Elevador MT3608 | 1 | Ajustable; ajustar a 5.0 V | Panel -> entrada del cargador
auxiliar_energia | Diodo Schottky 1N5817 | 1 | 1 A 20 V | Anti-retorno del panel
auxiliar_energia | Convertidor reductor Buck A | 1 | >= 3 A continuos (p. ej. XL4015) | 6.0 V exclusivo del MG995 | Ajustar antes de conectar
auxiliar_energia | Convertidor reductor Buck B | 1 | 2-3 A (p. ej. LM2596 o MP1584) | 5.0 V para logica | Ajustar antes de conectar
auxiliar_energia | Fusible lento 4 A + portafusible | 1 |  | Proteccion del cableado de bateria
auxiliar_energia | Interruptor basculante | 1 | >= 6 A; recorte 19x13 mm | Corte general | Verificar recorte del cajon
pasivo | Resistencia 1 kOhm 1/4 W | 2 |  | R1 y R5 divisores de los ECHO (serie)
pasivo | Resistencia 2 kOhm 1/4 W | 2 |  | R2 y R6 divisores de los ECHO (a GND)
pasivo | Resistencia 330 Ohm 1/4 W | 1 |  | R3 serie senal del servo
pasivo | Resistencia 10 kOhm 1/4 W | 1 |  | R4 pull-down senal del servo
pasivo | Resistencia 100 kOhm 1/4 W 1% | 4 |  | Divisores VBAT V6 y panel
pasivo | Resistencia 33 kOhm 1/4 W 1% | 2 |  | Divisores VBAT y V6
pasivo | Condensador ceramico 100 nF | 4 |  | 3 filtros ADC en la placa de control + 1 en la ESP32-CAM
pasivo | Condensador electrolitico 470 uF >= 10 V | 3 |  | Salida Buck B + placa de control + ESP32-CAM
pasivo | Condensador electrolitico 1000-2200 uF >= 10 V | 1 |  | Junto al conector del MG995
opcional | 74AHCT125 | 1 |  | Adaptador 3.3 V -> 5 V si el MG995 no responde a 3.3 V | Solo si falla la Prueba 3
montaje | Placa perforada 90x70 mm | 1 | Paso 2.54 mm | Placa de control | Ver Documentation/wiring/placa_control.md
montaje | Tira de pines hembra 1x15 | 2 | Paso 2.54 mm | Zocalo del ESP32
montaje | Conector JST-XH 2 pines (macho + hembra con cable) | 2 |  | J1 y J3
montaje | Conector JST-XH 4 pines (macho + hembra con cable) | 3 |  | J2 J4 y J5
montaje | Conector GX12 2 pines (macho aereo + hembra de panel) | 1 | Rosca 12 mm | Estacion solar remota -> tapa trasera del cajon 16 | Pin 1 = + (rojo) pin 2 = - (negro)
montaje | Cable bipolar de exterior AWG 20-22 | 1 | 3-5 m segun donde haya sol | Panel -> GX12 | Caida calculada ~0.05 V con 5 m
montaje | Cable de 4 hilos (apantallado opcional) AWG 24-26 | 1 | ~1.2 m | HC-SR04 de la tolva -> J5 | Por la ranura de la tapa y el conducto de la esquina; 20 cm flojos
montaje | Conector XT30 o JST-VH (par) | 2 |  | Potencia entre modulos (6 V y 5 V)
montaje | Cable AWG 20 | 1 | ~1 m rojo + 1 m negro | Bateria y servo
montaje | Cable AWG 22-26 | 1 | ~4 m surtido de colores | Senales y 5 V
montaje | Tornillo M3x10 (rosca en plastico) | 30 | 26 + 4 de repuesto | Uniones de modulos tapas pods bandeja viga pico y cajon | Ver Documentation/manual_armado
montaje | Tornillo M3x12 | 6 |  | Union base-cuerpo (4) y tapa de la capsula del sensor de nivel (2)
montaje | Tuerca M3 | 12 | 8 + 4 de repuesto | Pods y bandeja del ESP32
montaje | Tornillo M4x12 (cabeza moleteada o mariposa ideal) | 2 |  | Pivote de la estacion solar
montaje | Tuerca M4 + arandela M4 | 2 |  | Pivote de la estacion solar (tuerca alojada en 12b)
montaje | Bridas plasticas 2.5 mm | 6 |  | Cables (alivio de tension en la estacion solar)
montaje | Cinta doble faz de espuma (VHB) de exterior | 1 | ~20 cm | Panel en la bandeja 12b y modulos sin agujeros
montaje | Silicona neutra o termofusible | 1 |  | Fijar el HC-SR04 de la tolva en su capsula
impresion | Filamento PETG apto para alimentos | 1.5 | kg | Piezas en contacto con el alimento + tapa + estacion solar + 06 y 16 | ~1.25 kg laminado (Mechanical/plan_impresion.md) + reserva
impresion | Filamento PLA | 1.2 | kg | Estructura y capsulas de la torre | ~1.0 kg laminado + reserva (Elegoo Neptune 4 Plus)

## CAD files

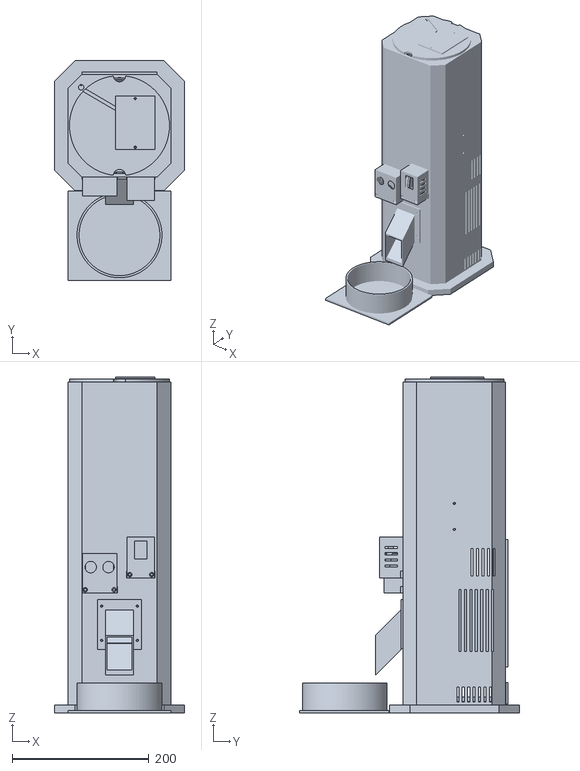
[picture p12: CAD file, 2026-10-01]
Mechanical/STL/00_Ensamblaje_Referencia_NO_IMPRIMIR.stl
190.0 x 321.0 x 490.6

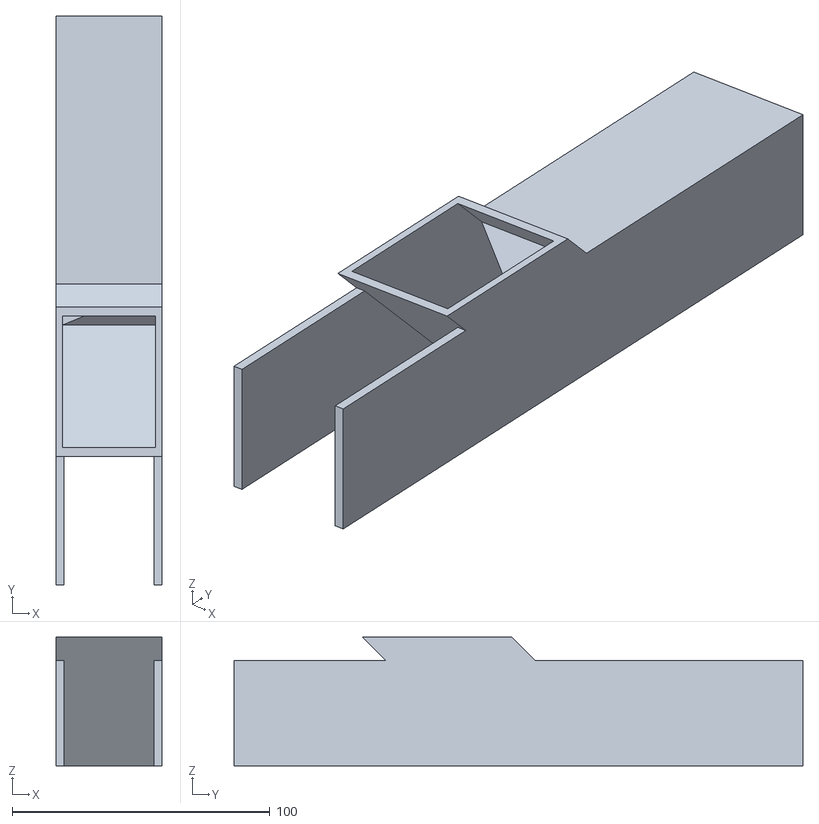
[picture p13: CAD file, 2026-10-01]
Mechanical/STL/09_Conducto_Alimento.stl
41.0 x 220.9 x 50.0

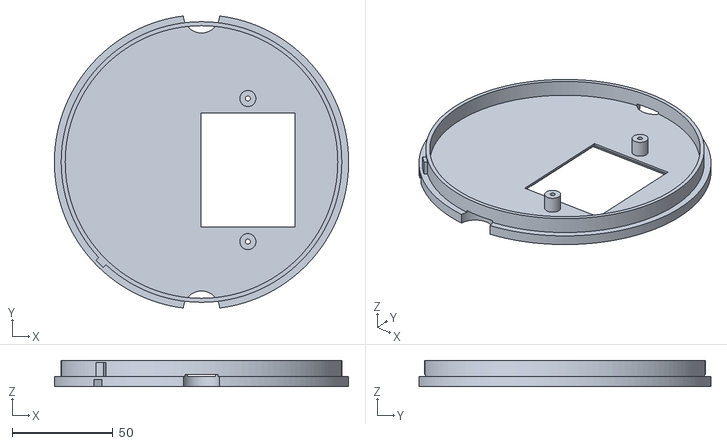
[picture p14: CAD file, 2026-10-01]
Mechanical/STL/13a_Tapa_Superior_Tolva.stl
146.0 x 144.8 x 13.0

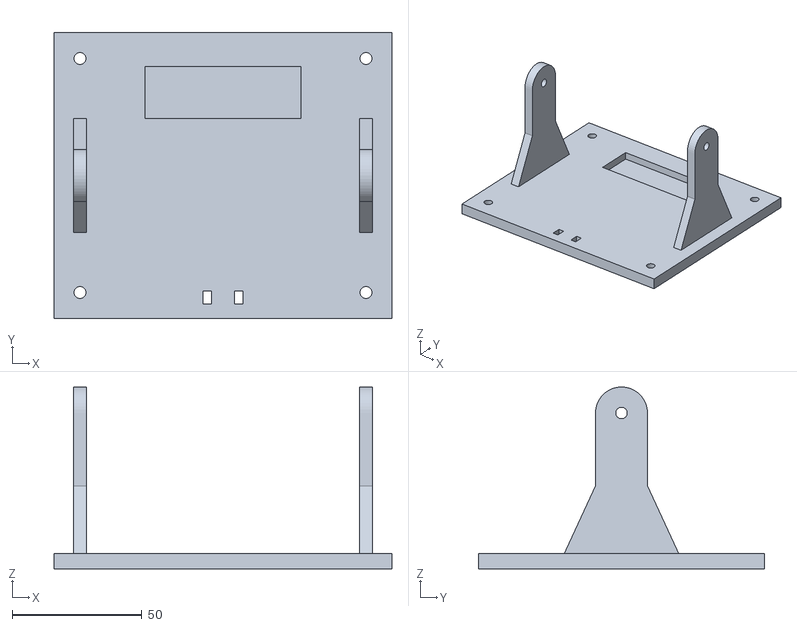
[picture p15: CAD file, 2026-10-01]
Mechanical/STL/12a_Estacion_Solar_Base.stl
130.0 x 110.0 x 70.0

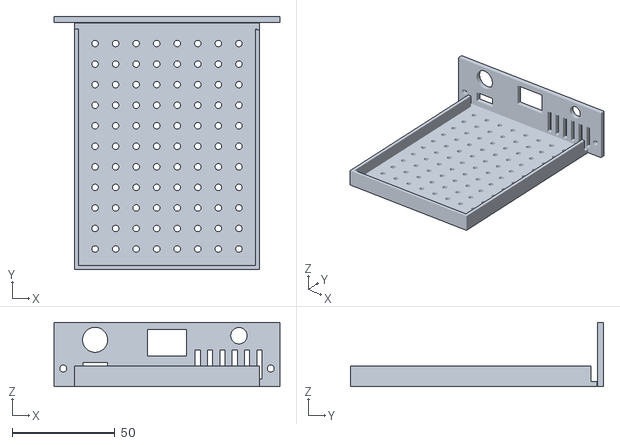
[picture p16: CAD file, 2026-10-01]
Mechanical/STL/16_Soporte_Estructural_Cajon_Energia.stl
110.0 x 123.2 x 31.3

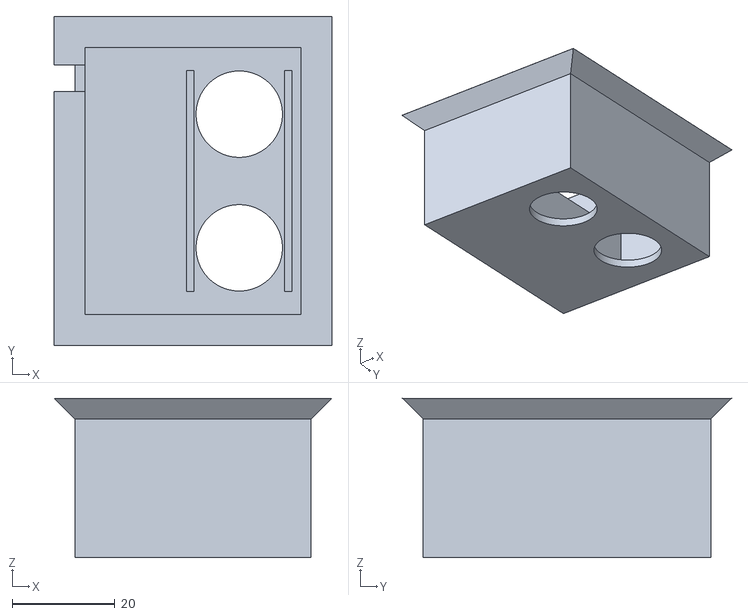
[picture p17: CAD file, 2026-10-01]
Mechanical/STL/13b_Capsula_Sensor_Nivel.stl
54.0 x 64.0 x 31.0

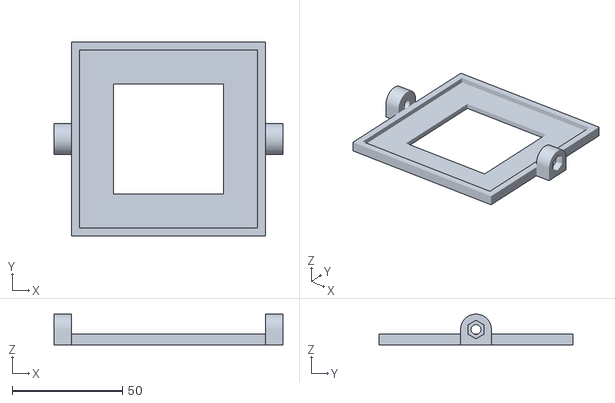
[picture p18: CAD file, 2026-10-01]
Mechanical/STL/12b_Estacion_Solar_Bandeja.stl
104.0 x 88.0 x 14.0

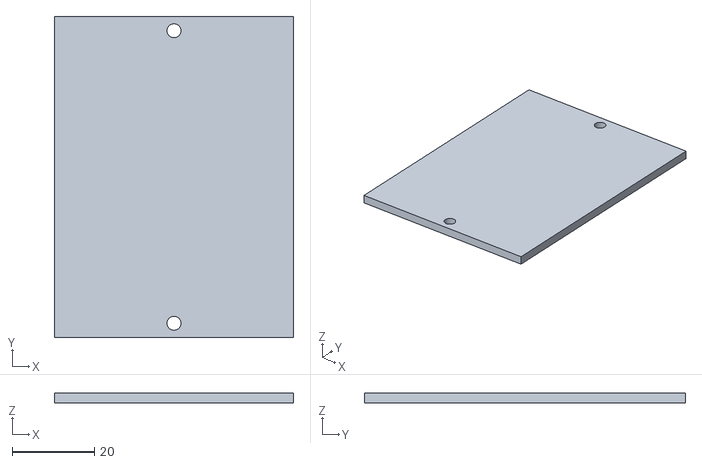
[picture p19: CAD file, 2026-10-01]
Mechanical/STL/13c_Tapa_Capsula_Sensor.stl
58.0 x 78.0 x 2.50

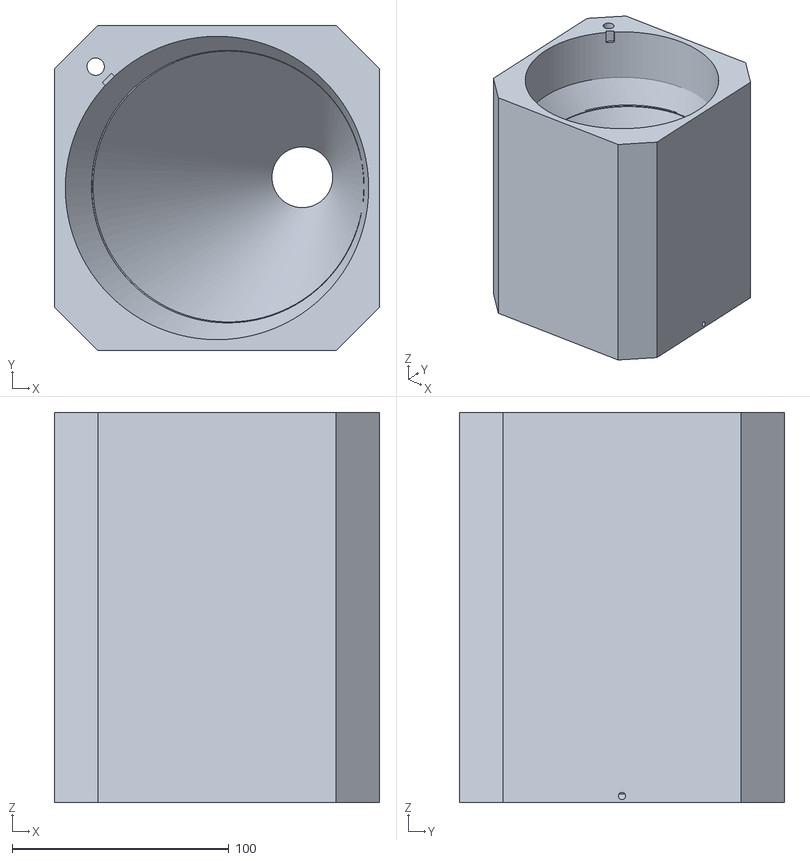
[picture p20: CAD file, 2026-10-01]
Mechanical/STL/07_Tolva.stl
150.0 x 150.0 x 180.0

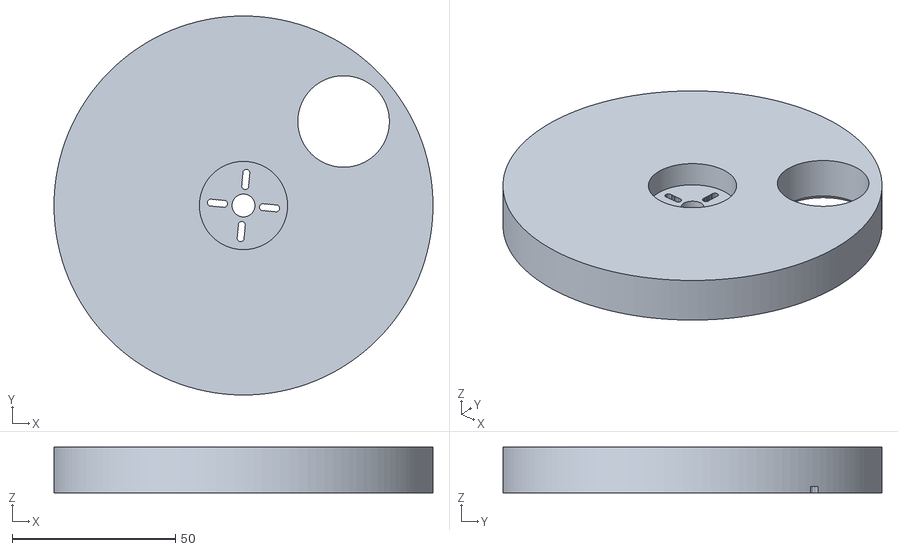
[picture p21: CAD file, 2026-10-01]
Mechanical/STL/08b_Disco_Dosificador.stl
116.0 x 116.0 x 14.0

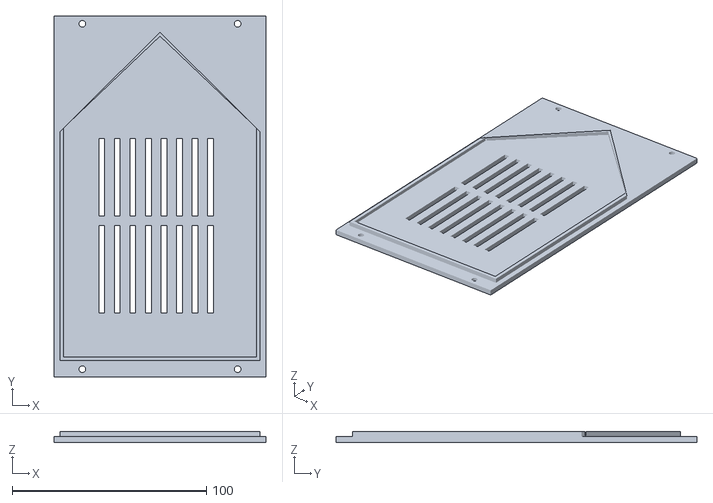
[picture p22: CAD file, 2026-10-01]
Mechanical/STL/14_Tapa_Lateral_Servicio.stl
109.0 x 186.0 x 5.50

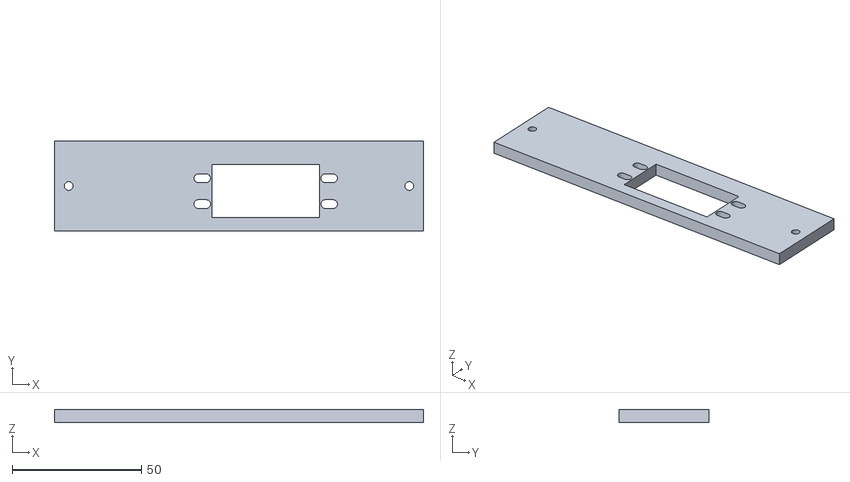
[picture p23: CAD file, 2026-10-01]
Mechanical/STL/06_Soporte_MG995.stl
143.0 x 35.0 x 5.00

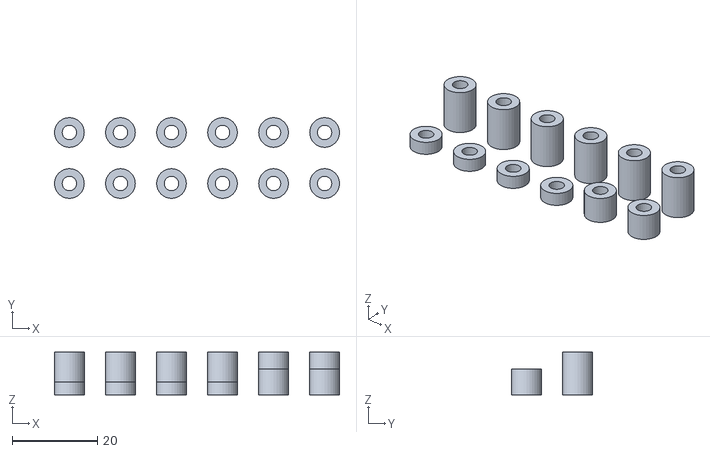
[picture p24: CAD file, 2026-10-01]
Mechanical/STL/15_Separadores.stl
67.0 x 19.0 x 10.0

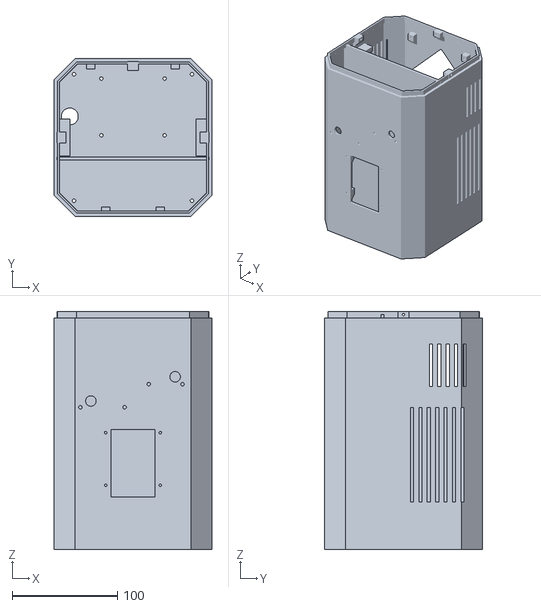
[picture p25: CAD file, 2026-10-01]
Mechanical/STL/02_Cuerpo_Principal.stl
150.0 x 150.0 x 226.0

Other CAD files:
Mechanical/STL/05_Modulo_ESP32.stl
Mechanical/STL/11_Comedero.stl
Mechanical/STL/10_Salida_Alimento.stl
Mechanical/STL/08c_Placa_Superior_Dosificador.stl
Mechanical/STL/01_Base_Torre.stl
Mechanical/STL/03_Modulo_HC_SR04.stl
Mechanical/STL/04_Modulo_ESP32_CAM.stl
Mechanical/STL/08a_Carcasa_Dosificador.stl
Mechanical/STL/08d_Placa_Base_Dosificador.stl

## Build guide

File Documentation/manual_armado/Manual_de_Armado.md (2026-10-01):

# Manual de armado · Dispensador inteligente de alimento para mascotas

**Torre modular impresa en 3D + estación solar remota + sensor de nivel en la tolva**

Torre armada

Este manual explica cómo pasar de las piezas impresas a la torre armada, paso por paso. Las piezas se imprimen
con los STL de [`Mechanical/STL`](../../Mechanical/STL) (ya orientados para la **Elegoo Neptune 4 Plus**) siguiendo el
[plan de impresión](../../Mechanical/plan_impresion.md). El cableado eléctrico está en la
[tabla de conexiones](../wiring/tabla_conexiones.md), el [esquema completo](../wiring/esquema_conexiones.svg) y la
[placa de control](../wiring/placa_control.md); aquí se indica **en qué momento** del armado conviene hacer cada parte.

> **Antes de empezar:** lea el manual completo una vez. Hay dos pasos que no se pueden hacer después sin desarmar:
> la bandeja del ESP32 y las cápsulas del frente se atornillan **antes** de unir el cuerpo a la base (paso 2), y el
> disco se calibra **antes** de colocar la placa superior (pasos 6 y 7).

---

## Índice

0. [Herramientas y tornillería](#0-herramientas-y-tornillería)
1. [Control de las piezas impresas](#1-control-de-las-piezas-impresas)
2. Pasos de armado
   [1 Base y cajón](#paso-1--base-01-y-cajón-de-energía-16) ·
   [2 Cuerpo](#paso-2--cuerpo-02-bandeja-05-y-cápsulas-03-04) ·
   [3 Conducto y pico](#paso-3--conducto-09-y-pico-10) ·
   [4 Servo](#paso-4--servo-mg995-y-viga-06) ·
   [5 Dosificador](#paso-5--carcasa-08a-y-placa-base-08d) ·
   [6 Disco](#paso-6--disco-dosificador-08b-y-calibración) ·
   [7 Placa superior](#paso-7--placa-superior-08c) ·
   [8 Tolva](#paso-8--tolva-07) ·
   [9 Tapa y sensor de nivel](#paso-9--tapa-13a-con-el-sensor-de-nivel-13b--13c) ·
   [10 Tapa trasera y comedero](#paso-10--tapa-de-servicio-14-y-comedero-11) ·
   [11 Estación solar](#paso-11--estación-solar-remota-12a--12b)
3. [Calibración del sensor de nivel](#3-calibración-del-sensor-de-nivel)
4. [Pruebas finales](#4-pruebas-finales)
5. [Uso diario, limpieza y desarme](#5-uso-diario-limpieza-y-desarme)
6. [Problemas frecuentes](#6-problemas-frecuentes)

---

## 0. Herramientas y tornillería

**Herramientas:** destornillador Phillips PH1 y PH2, llave o pinza para tuercas M3 (5,5 mm) y M4 (7 mm),
calibre (pie de rey), multímetro, cautín y estaño, termorretráctil, pistola de silicona caliente (o silicona neutra),
cúter o desbarbador, broca de 3,4 mm y de 2,5 mm (solo para repasar agujeros), cinta doble faz de espuma (VHB).

**Tornillería (total del proyecto):**

| Elemento | Cantidad | Dónde |
|---|---|---|
| Tornillo M3 × 10 (cabeza Phillips) | 26 (+4 de repuesto) | uniones de módulos, cápsulas, bandeja, viga, pico, tapa de servicio, cajón |
| Tornillo M3 × 12 | 6 | base ↔ cuerpo (4) y tapa de la cápsula del sensor de nivel (2) |
| Tuerca M3 | 8 (+4) | cápsulas 03/04 y bandeja 05 |
| Tornillo M4 × 12 (mejor cabeza moleteada o mariposa) | 2 | pivote de la estación solar |
| Tuerca M4 + arandela M4 | 2 + 2 | pivote de la estación solar |
| Tornillos del servo, horn redondo y su tornillo central | los que trae el MG995 | servo ↔ viga, horn ↔ disco |
| Bridas plásticas (precintos) 2,5 mm | 6 | cables |
| Tornillos para madera Ø4 o tacos (opcional) | 4 | fijar la estación solar al suelo o a un muro |

**Reglas para los tornillos en plástico:** los agujeros de Ø2,5 mm están hechos para que el tornillo M3 haga su propia
rosca. Atornille despacio, sin taladro, y pare en cuanto la cabeza apoye: si se pasa, la rosca se barre. Los agujeros
pasantes (Ø3,4 mm) deben dejar pasar el tornillo sin esfuerzo; si no, repáselos con la broca de 3,4 mm a mano.

---

## 1. Control de las piezas impresas

| Código | Pieza | Material | Control después de imprimir |
|---|---|---|---|
| 01 | Base de la torre | PLA | quitar la falda; los 4 pilares de las esquinas deben estar enteros |
| 02 | Cuerpo principal | PLA | probar que 08a entra en el labio superior sin forzar (holgura 0,3 mm) |
| 03 / 04 | Cápsulas HC-SR04 / ESP32-CAM | PLA | presentar el sensor y la cámara: deben entrar sin limar |
| 05 | Bandeja del ESP32 | PLA | la placa perforada de 90 × 70 mm desliza en las guías |
| 06 | Viga del servo | PETG | el MG995 entra en su ventana; orejas sobre las ranuras |
| 07 | Tolva | PETG | pasar el dedo por dentro del embudo: sin hilos ni gotas (el alimento debe deslizar). Ver el surco **MAX** |
| 08a | Carcasa del dosificador | PLA | — |
| 08b | Disco dosificador | PETG | cara inferior plana: apoyarlo en una mesa y comprobar que no se balancea |
| 08c / 08d | Placas superior y base | PETG | superficies de deslizamiento lisas; quitar rebabas de los agujeros de entrada y salida |
| 09 / 10 | Conducto y pico | PETG | mirar a contraluz: el interior debe estar libre |
| 11 | Comedero | PETG | — |
| 12a / 12b | Estación solar (base y bandeja) | PETG | la tuerca M4 entra en el hexágono de cada nudillo de 12b |
| 13a / 13b / 13c | Tapa, cápsula del sensor de nivel y su tapa | PETG | la cápsula 13b asienta en el avellanado de 13a quedando al ras |
| 14 | Tapa de servicio | PLA | — |
| 15 | Separadores | PLA | 12 tubos de 3, 6 y 10 mm |
| 16 | Cajón de energía | PETG | el interruptor encaja en su ventana de 19,2 × 13 mm |

> Si alguna pieza que encaja en otra queda justa, **lije la pieza interior** (el labio o la pestaña), no la exterior.

---

## 2. Pasos de armado

### Paso 1 · Base (01) y cajón de energía (16)

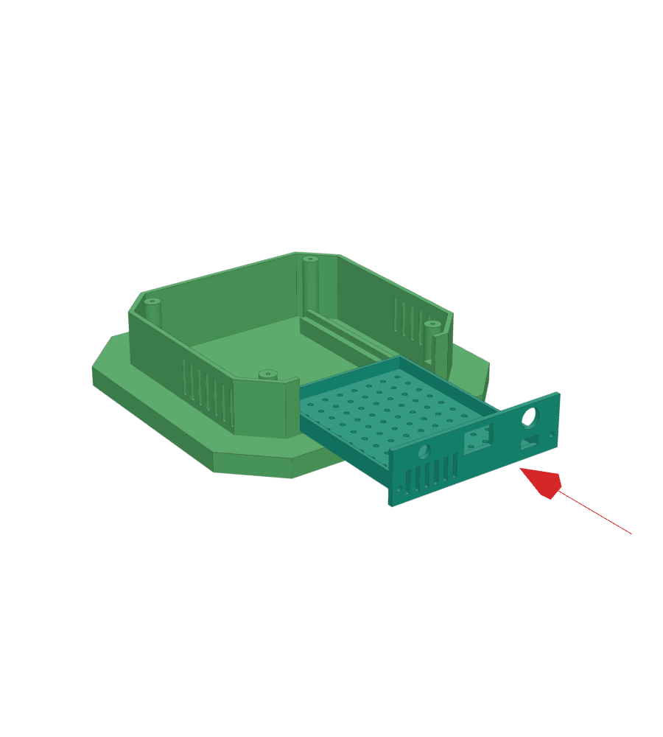
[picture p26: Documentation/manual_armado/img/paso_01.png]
Paso 1


**Piezas:** 01, 16, separadores 15 · **Tornillería:** 2 × M3×10 + los de cada módulo electrónico ·
**Antes:** módulos de energía ajustados (Buck A = 6,0 V, Buck B = 5,0 V, MT3608 = 5,0 V, con multímetro y sin carga).

1. Coloque en la tapa trasera del cajón: el **interruptor S1** (entra a presión en la ventana rectangular del centro),
   el **conector GX12 hembra** del panel (agujero redondo de 12 mm que está **encima** de la ventana pequeña del USB-C;
   el cuerpo por fuera y la tuerca por dentro) y el portafusible F1 o un LED en el agujero de Ø8 del otro lado. El USB-C
   del cargador debe quedar frente a su ventana pequeña.
2. Fije los módulos al piso del cajón usando la rejilla de agujeros (paso 10 mm) con tornillos M3 y separadores 15:
   portapilas 2S, BMS, cargador 2S, MT3608, Buck A, Buck B y la placa de los divisores. Los módulos sin agujeros se pegan
   con cinta doble faz de espuma.
3. Cablee el cajón según la [tabla de conexiones, sección 3](../wiring/tabla_conexiones.md#3-cajón-de-energía-pieza-16).
   Deje salir hacia arriba: el cable J1 (5 V), el cable de la ESP32-CAM (5 V), el cable J4 (mediciones) y el cable de
   potencia del servo (6 V).
4. Con S1 apagado y **sin** las celdas, revise con el multímetro que no haya continuidad entre + y − de cada salida.
   Coloque las celdas, encienda S1 y mida: VBAT 6,0–8,4 V, 6,0 V y 5,0 V. Apague S1.
5. Deslice el cajón en la base **desde atrás** hasta que la tapa trasera apoye, y atorníllelo con 2 × M3×10 en los
   agujeros de la tapa trasera.

✔ **Comprobación:** el cajón entra y sale sin tocar los cables; el interruptor y el GX12 quedan accesibles por detrás.

### Paso 2 · Cuerpo (02), bandeja (05) y cápsulas (03, 04)

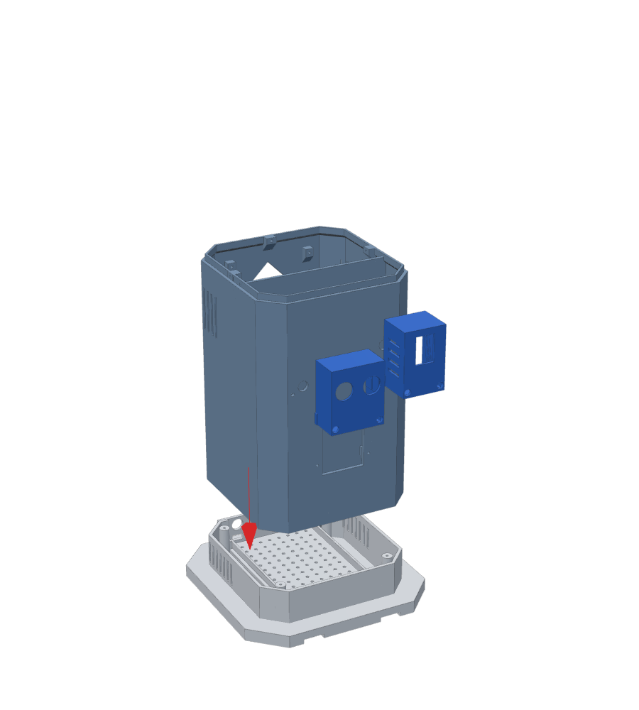
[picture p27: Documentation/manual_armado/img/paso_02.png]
Paso 2


**Piezas:** 02, 03, 04, 05 · **Tornillería:** 8 × M3×10 + 8 tuercas M3; 4 × M3×12 para unir con la base.

1. **Bandeja del ESP32 (05):** apóyela en el piso de la bahía trasera de 02 (detrás del tabique) y atorníllela con
   4 × M3×10; las tuercas van por **debajo** del piso. Hágalo ahora: después la base tapa el acceso.
2. **Cápsula 03 (HC-SR04 de presencia, frente izquierda):** coloque el sensor con los pines hacia abajo, pase el cable de
   4 hilos por el agujero del frente y fije la cápsula con 2 × M3×10 + tuercas por dentro de la pared.
3. **Cápsula 04 (ESP32-CAM, frente derecha):** coloque la cámara (lente hacia el frente, con 470 µF + 100 nF ya soldados
   a sus pines de 5 V/GND), pase el cable de 5 V por su agujero y fíjela con 2 × M3×10 + tuercas.
4. Lleve los cables de 03 y 04 a la bahía trasera por los pasos izquierdo y derecho del tabique. **Ningún cable cruza el
   canal de alimento.**
5. Pase los cables que suben del cajón (J1, J4, cámara, 6 V del servo) por el agujero del piso de 02.
6. Apoye 02 sobre la base 01 y atorníllelo con 4 × M3×12 **desde arriba**, a través del piso, a los pilares de 01.

✔ **Comprobación:** la torre no cabecea; los cables no quedan pellizcados entre 01 y 02.

### Paso 3 · Conducto (09) y pico (10)

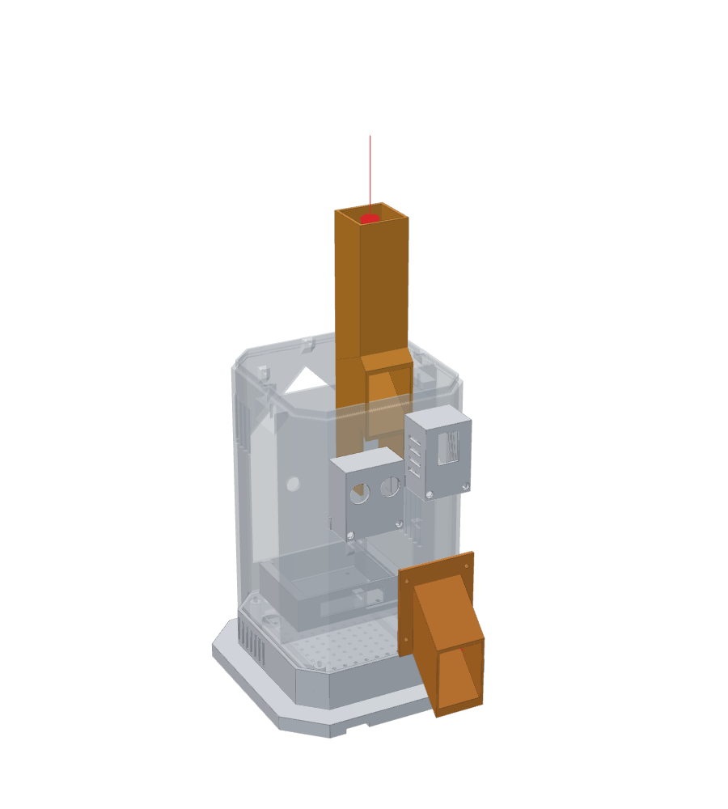
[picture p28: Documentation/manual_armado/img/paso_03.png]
Paso 3


**Piezas:** 09, 10 · **Tornillería:** 4 × M3×10.

1. Baje el conducto 09 **desde arriba** por la zona frontal de 02 (delante del tabique), con el codo hacia el frente,
   hasta que apoye en el piso. Su boca superior queda centrada bajo la futura salida del disco.
2. Coloque el pico 10 desde fuera, encajado en la abertura del frente, y atornille su brida con 4 × M3×10.

✔ **Comprobación:** deje caer una croqueta por la boca superior de 09: debe salir por el pico sin trabarse.

### Paso 4 · Servo MG995 y viga (06)

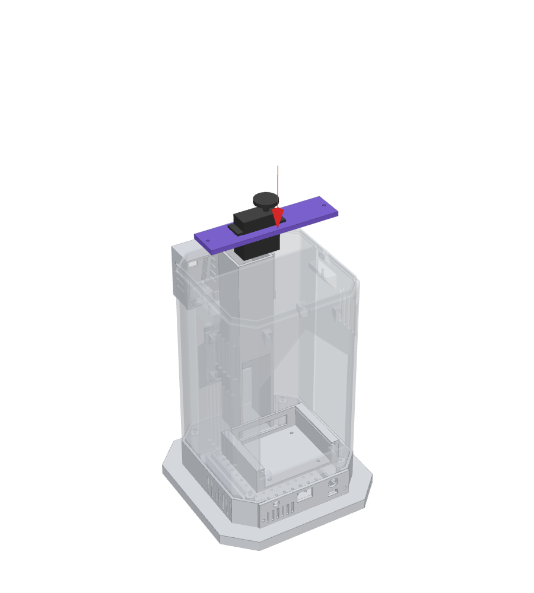
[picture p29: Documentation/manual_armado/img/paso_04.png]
Paso 4


**Piezas:** 06, MG995, separadores de 3 mm · **Tornillería:** 2 × M3×10 + los 4 tornillos del servo.

1. **Centre el servo antes de montarlo:** en la mesa de trabajo, conéctelo a J3 de la placa de control y al 6 V del
   Buck A, cargue el firmware y envíe por el monitor serie `SERVO 1500` (ver [`ESP32/README.md`](../../ESP32/README.md)).
   No gire el eje a mano después.
2. Atornille el MG995 a la viga 06 con sus 4 tornillos (las ranuras permiten ajustar).
3. Apoye la viga en las dos ménsulas internas de 02 y atorníllela con 2 × M3×10. Si el eje queda bajo, ponga
   separadores de 3 mm (15) como calces.
4. Lleve el cable del servo a la bahía trasera: naranja → J3 SIG, marrón → J3 GND **y** GND del Buck A, rojo → 6 V del
   Buck A (con el condensador de 1000–2200 µF junto al servo).

✔ **Comprobación:** la estría del servo queda en el centro de la torre, apuntando hacia arriba.

### Paso 5 · Carcasa (08a) y placa base (08d)

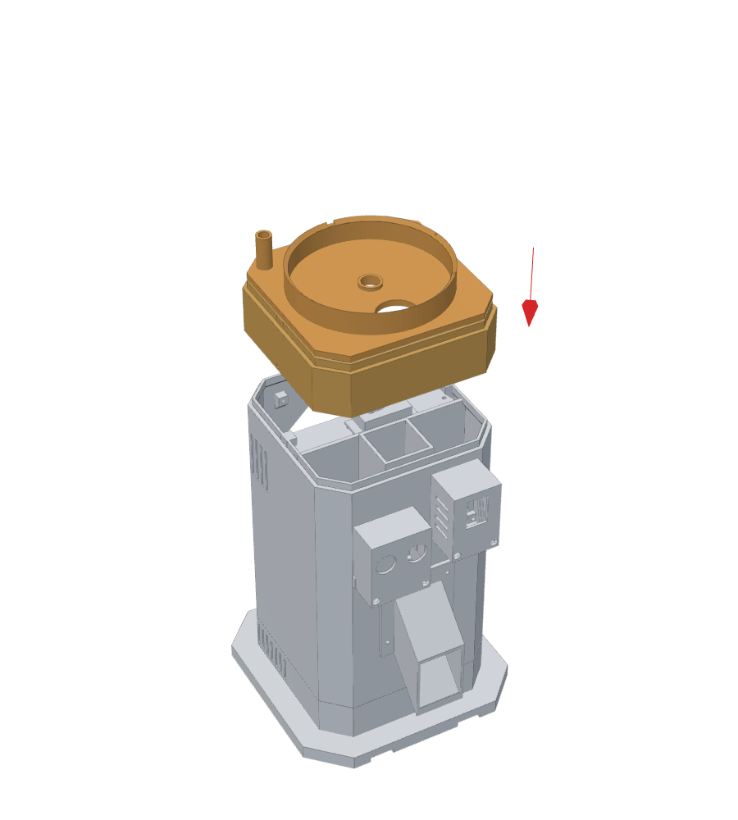
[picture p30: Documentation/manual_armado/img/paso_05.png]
Paso 5


**Piezas:** 08a, 08d · **Tornillería:** 3 × M3×10 (radiales).

1. Coloque la carcasa 08a sobre el labio de 02 y fíjela con 3 × M3×10 desde fuera, en el centro de las paredes
   izquierda, derecha y trasera (los tornillos roscan en los tetones del labio).
2. Baje la placa base 08d dentro de 08a hasta que apoye en el labio de 02, con el **agujero de salida (Ø32) hacia el
   frente** y el tubito del conducto de cables en la **esquina trasera izquierda**.

✔ **Comprobación:** la estría del servo asoma por el agujero central de 08d; la salida de 08d queda sobre el conducto 09.

### Paso 6 · Disco dosificador (08b) y calibración

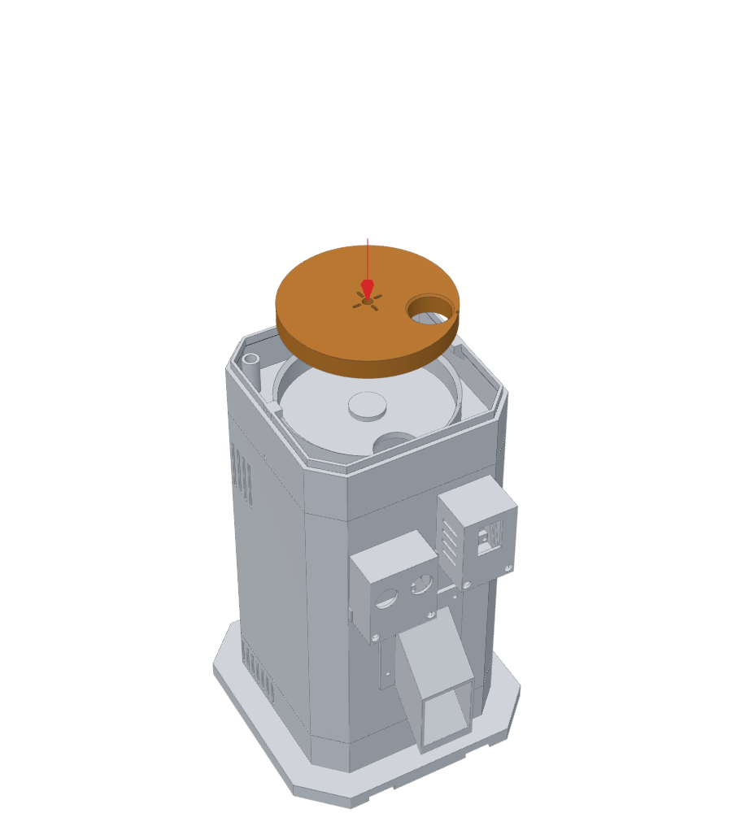
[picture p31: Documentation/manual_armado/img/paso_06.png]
Paso 6


**Piezas:** 08b, horn redondo del MG995 · **Tornillería:** tornillos del horn y tornillo central del servo.

1. Atornille el horn redondo al disco 08b (cara inferior) con los tornillitos que trae el servo.
2. Con el servo en 1500 µs, apoye el disco con su marca frente a la marca **CERRADO** de 08d y encájelo en la estría.
   Coloque el tornillo central.
3. Gírelo con `SERVO <µs>` y compruebe que no roce en ningún punto (debe quedar ~0,5 mm de luz bajo el disco).
4. **Calibre ahora** las posiciones ENTRADA, CERRADO y SALIDA con las marcas de 08d a la vista
   ([`Documentation/calibration`](../calibration)) y anótelas en `config.h`.

✔ **Comprobación:** `CICLO 1` mueve el disco ENTRADA → SALIDA → CERRADO sin golpes ni roces.

### Paso 7 · Placa superior (08c)

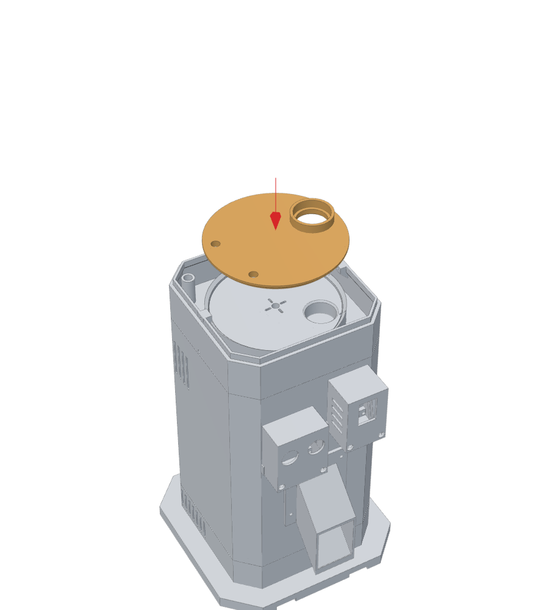
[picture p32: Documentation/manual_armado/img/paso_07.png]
Paso 7


**Piezas:** 08c · **Sin tornillos.**

1. Baje la placa superior 08c sobre el asiento cónico de 08d con la **chaveta** en su chavetero (solo entra en una
   posición). El zócalo (anillo saliente) queda sobre la entrada, a la derecha mirando la torre de frente.

✔ **Comprobación:** `CICLO 1` sigue funcionando igual (si roza, la placa no asentó: levántela y vuelva a bajarla).

### Paso 8 · Tolva (07)

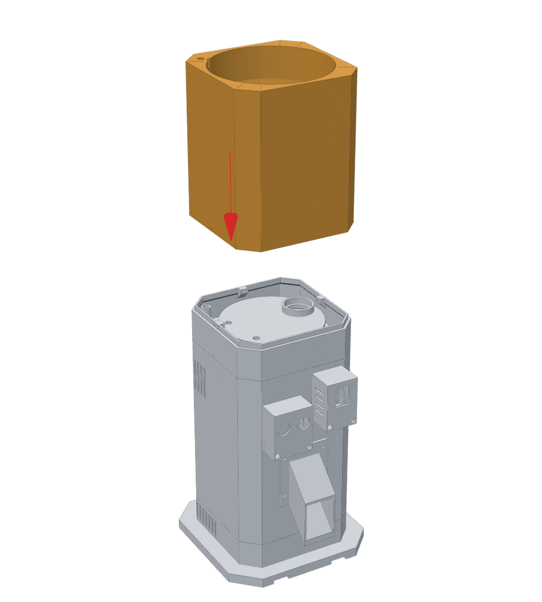
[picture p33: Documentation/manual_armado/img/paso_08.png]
Paso 8


**Piezas:** 07 · **Tornillería:** 3 × M3×10 (radiales).

1. Baje la tolva sobre el labio de 08a: la **boca inferior del embudo entra en el zócalo de 08c** y el tubo de cables de
   la esquina trasera izquierda queda alineado con el de 08d.
2. Fíjela con 3 × M3×10 en el centro de las paredes izquierda, derecha y trasera.

✔ **Comprobación:** mire desde arriba: la boca del embudo coincide con la entrada de 08c; por el tubo de la esquina se
ve la bahía trasera.

### Paso 9 · Tapa (13a) con el sensor de nivel (13b + 13c)

*Recomendación del profesor: un segundo HC-SR04 dentro de la tolva avisa cuando la comida se está acabando.*

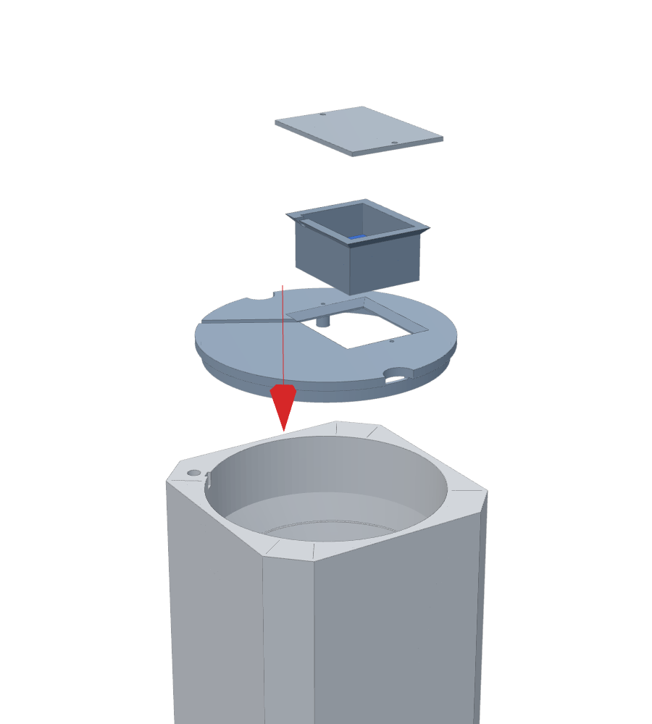
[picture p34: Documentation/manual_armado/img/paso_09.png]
Paso 9


Detalle en corte de la tapa con el sensor

**Piezas:** 13a, 13b, 13c, HC-SR04 n.º 2 · **Tornillería:** 2 × M3×12 · cable de 4 hilos de ~120 cm.

1. **Cable:** suelde (o conecte con un conector Dupont de 4 vías) el cable al HC-SR04 n.º 2 en el orden VCC-TRIG-ECHO-GND
   y aísle con termorretráctil.
2. **Sensor en la cápsula 13b:** apoye la placa con los **dos transductores hacia abajo**, pasándolos por los agujeros
   del piso de la cápsula; la placa descansa en los dos nervios. Los transductores quedan aproximadamente al ras de la
   cara inferior (si sobresalen un poco, no importa; si quedan hundidos, lime un poco los nervios).
   Fije la placa con dos gotas de silicona en los nervios (no tape los transductores). Saque el cable por la **muesca**
   del borde de la cápsula.
3. **Cápsula en la tapa:** desde arriba, introduzca la cápsula en la abertura de la tapa 13a: el ala a 45° asienta en el
   avellanado y queda al ras de la cara superior. Acomode el cable en la **ranura** que va hacia la llave de la tapa.
4. Coloque la tapa de la cápsula 13c y atorníllela con 2 × M3×12 a los tetones de 13a. El cable queda apretado en la
   muesca: no se tironea de las soldaduras.
5. **Recorrido del cable:** desde el borde de la tapa, el cable baja por el **tubo de la esquina trasera izquierda**
   (tolva 07 → placa base 08d) hasta la bahía trasera de 02, y llega a **J5** de la placa de control
   (GND-ECHO-TRIG-VCC de izquierda a derecha en el borde superior de la placa; el mismo cable, girado).
   Deje **~20 cm flojos** entre la tapa y el tubo: así la tapa se levanta y se apoya al costado para cargar alimento.
6. Coloque la tapa: la **llave** del aro inferior entra en la ranura de la tolva (esquina trasera izquierda). Solo hay
   una posición, y siempre es la misma: así la calibración del sensor no cambia al abrir y cerrar.

✔ **Comprobación:** con la tolva vacía, el comando serie `NIVEL` responde una distancia (no "sin lectura").

⚠ **Nunca llene por encima del surco MAX** del embudo: el HC-SR04 no mide a menos de 2 cm, y el surco está a 3 cm
de los transductores.

### Paso 10 · Tapa de servicio (14) y comedero (11)

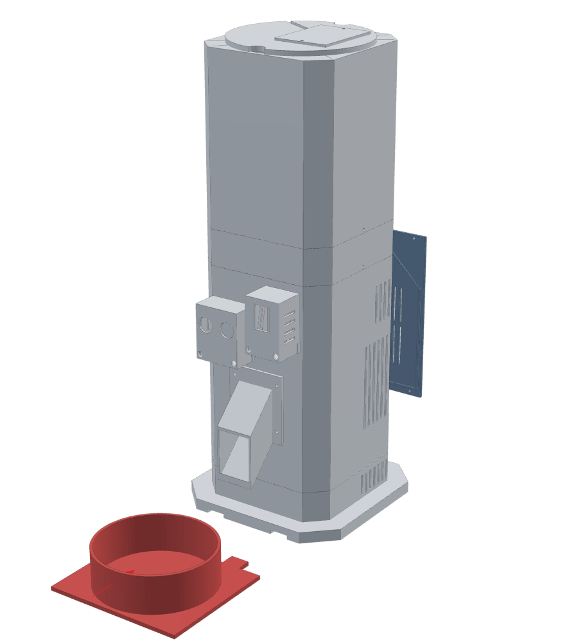
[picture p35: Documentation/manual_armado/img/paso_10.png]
Paso 10


**Piezas:** 14, 11 · **Tornillería:** 4 × M3×10.

1. Coloque la placa de control (con el ESP32) en la bandeja 05 deslizándola por las guías y conecte J1 a J5.
2. Cierre la bahía trasera con la tapa de servicio 14 (4 × M3×10). Las ranuras quedan como ventilación.
3. Encaje el comedero 11 por delante: sus dos lengüetas entran **bajo el plinto** de la base. Sin tornillos.

✔ **Comprobación:** el pico deja caer el alimento dentro del cuenco del comedero.

### Paso 11 · Estación solar remota (12a + 12b)

*Recomendación del profesor: el panel solar puede ir aparte del sistema, alejado del dispensador.*

Paso 11

**Piezas:** 12a, 12b, panel solar · **Tornillería:** 2 × M4×12, 2 tuercas M4, 2 arandelas M4, 1 brida, 4 tornillos
para madera o tacos (opcional) · cable bipolar de exterior de 3–5 m + conector GX12 macho de 2 pines.

1. **Mida el panel** y, si no es de 80 × 80 mm, cambie `PANEL_W`, `PANEL_H` y `PANEL_E` en `generar_stl.py` y vuelva a
   generar 12b antes de imprimirla.
2. Suelde el cable bipolar a los terminales del panel (rojo = +, negro = −) y aísle. Pase el cable por la ventana central
   de la bandeja 12b y pegue el panel en el alojamiento con cinta doble faz de exterior.
3. Suelde el otro extremo del cable al **GX12 macho**: pin 1 = + (rojo), pin 2 = − (negro). Compruebe la polaridad con el
   multímetro al sol antes de enchufarlo.
4. Introduzca una **tuerca M4** en el hexágono de la cara exterior de cada nudillo de 12b.
5. Coloque la bandeja entre las orejas de la base 12a y pase un **M4×12 con arandela** desde fuera de cada oreja hasta
   la tuerca.
6. Ajuste la inclinación: aproximadamente la **latitud del lugar** (mínimo 10–15° para que escurran el agua y el polvo),
   con el panel mirando hacia el **ecuador** (al norte en el hemisferio sur, al sur en el hemisferio norte). Apriete los
   dos tornillos: la fricción mantiene el ángulo (0–75°).
7. Sujete el cable con una brida a la base (dos ranuras y un túnel por debajo) para que un tirón no llegue a las
   soldaduras. Fije la base con 4 tornillos o lastre en el bolsillo (por ejemplo, tuercas o arandelas pegadas).
8. Lleve el cable hasta la torre y, **con S1 apagado**, enchufe el GX12 en la tapa trasera del cajón.

✔ **Comprobación:** con el panel al sol, el comando serie `ENERGIA` muestra la tensión del panel (unos 3 V).

> Con 0,3 W el panel es **demostrativo**: la carga principal es el USB-C (ver el balance en
> [`Documentation/power`](../power)). Ubicarlo donde haya sol directo es lo que más mejora su aporte.

---

## 3. Calibración del sensor de nivel

El firmware convierte la distancia en **porcentaje del volumen** (el embudo se estrecha: con el 20 % de la altura queda
solo ~5 % del alimento; la tabla altura → volumen se calcula con el modelo 3D, ver `NivelGeometria.h`).

1. Con la tolva **vacía** y la tapa puesta, envíe `NIVEL VACIO` por el monitor serie.
2. Cargue alimento **hasta el surco MAX**, nivélelo con la mano y envíe `NIVEL LLENO`.
3. Envíe `NIVEL`: debe responder cerca de 100 %. Los valores quedan guardados en la memoria del ESP32.

| Volumen restante | Qué pasa |
|---|---|
| < 20 % (≈125 cm³) tres lecturas seguidas | alerta **COMIDA_BAJA** al PC (panel web) y, si se configuró ntfy, al celular |
| ≤ 3 % | alerta **COMIDA_AGOTADA**: el dispensador no entrega raciones (girar en vacío no alimenta) |
| > 30 % después de recargar | alerta **COMIDA_REPUESTA**: todo vuelve a la normalidad |

Los umbrales están en la sección 8 de `config.h`. Para convertir volumen en gramos, pese una taza de su alimento
(densidad aparente) — depende de cada marca.

---

## 4. Pruebas finales

1. Monitor serie: `ESTADO` (sin errores), `DIST` (presencia), `NIVEL`, `ENERGIA`.
2. Servidor de visión en el PC en marcha; panel web en `http://IP-DEL-PC:8000/`.
3. Acerque una foto impresa de un perro o un gato al frente: el ESP32 detecta, fotografía, clasifica y dispensa
   (1 = PERRO, 2 = GATO). Con una imagen dudosa **no** debe dispensar.
4. Pese varias raciones y ajuste los ciclos por clase (ver `Documentation/calibration`).
5. Saque alimento hasta bajar del 20 %: en menos de 3 minutos debe aparecer la alerta en el panel web.

---

## 5. Uso diario, limpieza y desarme

* **Cargar alimento:** levantar la tapa por las muescas laterales, apoyarla al costado (el cable tiene holgura),
  llenar hasta el surco MAX y volver a colocarla con la llave atrás a la izquierda.
* **Limpieza (piezas en contacto con el alimento):** quitar los 3 tornillos de la tolva y levantarla; la placa superior
  08c y el disco 08b salen a mano (el disco, quitando el tornillo central del servo). Lavar 07, 08b, 08c, 08d, 09, 10 y
  11 con agua tibia y jabón — **no** en lavavajillas — y secar bien antes de volver a cargar.
* **Electrónica:** se accede quitando la tapa de servicio 14; el cajón de energía sale por detrás sin desarmar la torre.
* **Estación solar:** limpiar el panel con un paño húmedo; revisar cada tanto el apriete de los tornillos M4.

---

## 6. Problemas frecuentes

| Síntoma | Causa probable | Solución |
|---|---|---|
| El disco roza o se traba | 08c mal asentada, rebabas, servo bajo | asentar 08c con la chaveta; desbarbar; calzar la viga con separadores |
| Caen croquetas sin pedirlo | disco no está en CERRADO | recalibrar la posición CERRADO (paso 6) |
| La tolva no baja hasta el fondo | la boca no entra en el zócalo de 08c | girar la tolva: el tubo de cables va atrás a la izquierda |
| La tapa no entra | la llave no está frente a su ranura | girar la tapa hasta que la llave quede atrás a la izquierda |
| `NIVEL` dice "sin lectura" | cable cortado o invertido en J5 | revisar el orden GND-ECHO-TRIG-VCC en J5 y la continuidad |
| El nivel salta mucho | alimento amontonado bajo el sensor | nivelar al cargar; recalibrar VACIO/LLENO |
| `ENERGIA` muestra panel 0 V al sol | GX12 desenchufado o polaridad invertida | revisar pin 1 = +, pin 2 = − |
| La bandeja del panel se cae | tornillos M4 flojos | apretar; poner arandelas a ambos lados de las orejas |

---

*Las imágenes de los pasos se generan a partir del mismo modelo paramétrico que los STL (`Mechanical/generar_stl.py`).*

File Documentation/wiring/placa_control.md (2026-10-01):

# Placa de control — lista de cables

Generada por `generar_placa_control.py` (no editar a mano). Coordenadas (columna, fila) desde la
esquina superior izquierda, vista desde el lado de los componentes. Ver `placa_control.svg`.

## Componentes

| Ref. | Valor / función | Agujeros |
|---|---|---|
| ESP32 | DevKit V1 30 pines sobre 2 tiras hembra de 15 | fila A (EN…VIN): (3,18)…(17,18); fila B (D23…3V3): (3,8)…(17,8) |
| J1 | J1 5 V | GND (33, 2), 5V (33, 3) |
| J2 | J2 HC-SR04 | VCC (33, 4), TRIG (33, 5), ECHO (33, 6), GND (33, 7) |
| J3 | J3 SERVO señal | SIG (33, 9), GND (33, 10) |
| J4 | J4 MEDICIÓN | VBAT (33, 12), V6 (33, 13), VPAN (33, 14), GND (33, 15) |
| J5 | J5 NIVEL TOLVA | GND (6, 2), ECHO (7, 2), TRIG (8, 2), VCC (9, 2) |
| R5 | R5 1k | 1 (7, 3), 2 (7, 7) |
| R6 | R6 2k | 1 (6, 7), 2 (2, 7) |
| R1 | R1 1k | 1 (31, 6), 2 (27, 6) |
| R2 | R2 2k | 1 (24, 6), 2 (24, 10) |
| R3 | R3 330 | 1 (31, 9), 2 (27, 9) |
| R4 | R4 10k | 1 (27, 11), 2 (27, 15) |
| C1 | C1 100n | 1 (25, 23), 2 (25, 25) |
| C2 | C2 100n | 1 (29, 22), 2 (29, 24) |
| C3 | C3 100n | 1 (31, 21), 2 (31, 23) |
| C4 | C4 470µF | + (21, 3), - (21, 5) |

Bus GND en U: agujeros (1,1) a (35,1), (35,1) a (35,26) y (3,26) a (35,26) unidos con estaño o alambre desnudo.

## Cables (soldar uno por uno y tachar)

| N.º | Red | Desde | Hasta | Recorrido (dobleces) |
|---|---|---|---|---|
| 1 | 5V | J1.5V (33, 3) | J2.VCC (33, 4) | (recto) |
| 2 | 5V | J1.5V (33, 3) | C4.+ (21, 3) | (recto) |
| 3 | 5V | C4.+ (21, 3) | J5.VCC (9, 2) | (21, 2) |
| 4 | 5V | J5.VCC (9, 2) | ESP32.A.VIN (17, 18) | (9, 7) → (18, 7) → (18, 18) |
| 5 | GND | J1.GND (33, 2) | bus GND (33, 1) | (recto) |
| 6 | GND | J2.GND (33, 7) | bus GND (35, 7) | (recto) |
| 7 | GND | J3.GND (33, 10) | bus GND (35, 10) | (recto) |
| 8 | GND | J4.GND (33, 15) | bus GND (35, 15) | (recto) |
| 9 | GND | J5.GND (6, 2) | bus GND (6, 1) | (recto) |
| 10 | GND | ESP32.A.GND (16, 18) | bus GND (16, 26) | (recto) |
| 11 | GND | R2.2 (24, 10) | bus GND (24, 26) | (recto) |
| 12 | GND | R4.2 (27, 15) | bus GND (27, 26) | (recto) |
| 13 | GND | R6.2 (2, 7) | bus GND (2, 1) | (recto) |
| 14 | GND | C1.2 (25, 25) | bus GND (25, 26) | (recto) |
| 15 | GND | C2.2 (29, 24) | bus GND (29, 26) | (recto) |
| 16 | GND | C3.2 (31, 23) | bus GND (31, 26) | (recto) |
| 17 | GND | C4.- (21, 5) | bus GND (21, 26) | (recto) |
| 18 | TRIG | J2.TRIG (33, 5) | ESP32.A.D26 (11, 18) | (25, 5) → (25, 19) → (11, 19) |
| 19 | ECHO_5V | J2.ECHO (33, 6) | R1.1 (31, 6) | (recto) |
| 20 | ECHO_3V3 | R1.2 (27, 6) | R2.1 (24, 6) | (recto) |
| 21 | ECHO_3V3 | R2.1 (24, 6) | ESP32.A.D34 (6, 18) | (23, 6) → (23, 24) → (6, 24) |
| 22 | SERVO_GPIO | R3.2 (27, 9) | R4.1 (27, 11) | (recto) |
| 23 | SERVO_GPIO | R4.1 (27, 11) | ESP32.A.D25 (10, 18) | (26, 11) → (26, 20) → (10, 20) |
| 24 | SERVO_SIG | J3.SIG (33, 9) | R3.1 (31, 9) | (recto) |
| 25 | VBAT_S | J4.VBAT (33, 12) | C1.1 (25, 23) | (28, 12) → (28, 23) |
| 26 | VBAT_S | C1.1 (25, 23) | ESP32.A.D35 (7, 18) | (7, 23) |
| 27 | V6_S | J4.V6 (33, 13) | C2.1 (29, 22) | (30, 13) → (30, 22) |
| 28 | V6_S | C2.1 (29, 22) | ESP32.A.D32 (8, 18) | (8, 22) |
| 29 | VPAN_S | J4.VPAN (33, 14) | C3.1 (31, 21) | (32, 14) → (32, 21) |
| 30 | VPAN_S | C3.1 (31, 21) | ESP32.A.D33 (9, 18) | (9, 21) |
| 31 | TRIG2 | J5.TRIG (8, 2) | ESP32.B.D19 (8, 8) | (recto) |
| 32 | ECHO2_5V | J5.ECHO (7, 2) | R5.1 (7, 3) | (recto) |
| 33 | ECHO2_3V3 | R5.2 (7, 7) | ESP32.B.D21 (7, 8) | (recto) |
| 34 | ECHO2_3V3 | R5.2 (7, 7) | R6.1 (6, 7) | (recto) |

## Arnés de cables de la torre

Longitudes estimadas sobre el modelo 3D (recorrido por los pasos del piso y del tabique) con ~30 % de
holgura; cortar un poco más largo y ajustar al montar. Conectores entre módulos recomendados: JST-XH
(señal) y XT30 o JST-VH (potencia), para poder separar los módulos sin desoldar.

| Cable | Desde | Hasta | Conductores | Sección | Longitud aprox. |
|---|---|---|---|---|---|
| J1 | Bus 5 V del cajón (Buck B) | J1 de la placa de control | 5V, GND | AWG 22 | 25 cm |
| J4 | Divisores del cajón | J4 de la placa de control | VBAT, V6, VPAN, GND | AWG 24–26 | 25 cm |
| J2 | J2 de la placa | HC-SR04 de presencia (cápsula 03, paso izquierdo del tabique) | VCC, TRIG, ECHO, GND | AWG 24–26 | 30 cm |
| J5 | J5 de la placa | HC-SR04 de nivel (cápsula 13b en la tapa): ranura de la tapa → conducto de la esquina trasera izquierda (07, 08d) → bahía trasera de 02 | VCC, TRIG, ECHO, GND (cable de 4 hilos, mejor apantallado) | AWG 24–26 | 120 cm (incluye 20 cm flojos para levantar la tapa) |
| J3 | J3 de la placa | Cables naranja (señal) y marrón (GND) del MG995 | SIG, GND | AWG 24 | 20 cm (el cable del MG995 suele alcanzar) |
| Servo 6 V | Buck A del cajón (+ C1 1000–2200 µF junto al servo) | Cable rojo (+) y marrón (−) del MG995 | 6V, GND | **AWG 20** | 40 cm |
| Cámara | Bus 5 V del cajón | ESP32-CAM (cápsula 04, paso derecho del tabique; 470 µF + 100 nF en la cápsula) | 5V, GND | AWG 22 | 45 cm |
| Panel | Panel solar en la estación remota (12a/12b) | Conector GX12 de 2 pines en la tapa del cajón 16 → elevador MT3608 y divisor del panel | +, − | AWG 20–22 (bipolar, exterior) | 3–5 m según dónde haya sol (medir) |

## Conectores de la placa

| Conector | Pin | Va a |
|---|---|---|
| J1 | 5V / GND | Bus de 5 V del cajón de energía (Buck B) |
| J2 | VCC / TRIG / ECHO / GND | HC-SR04 (cápsula 03) |
| J3 | SIG / GND | Cable naranja y marrón del MG995 (el rojo va al Buck A de 6 V, NO a esta placa) |
| J4 | VBAT / V6 / VPAN / GND | Salidas de los divisores 100k/33k, 100k/33k y 100k/100k montados en el cajón |
| J5 | GND / ECHO / TRIG / VCC (de izquierda a derecha) | HC-SR04 de nivel en la tapa de la tolva (el mismo cable de 4 hilos, girado 180°) |

Antes de colocar el ESP32: con el multímetro, comprobar que no hay continuidad entre 5V y GND
ni entre las redes ECHO_5V / ECHO2_5V y el ESP32; con J1 alimentado y los HC-SR04 conectados, medir
≤ 3,4 V en los agujeros de D34 y D21 al disparar (comandos serie DIST y NIVEL).

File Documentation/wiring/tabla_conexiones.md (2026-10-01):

# Tabla de conexiones punto a punto

Complementa al [esquema completo](esquema_conexiones.svg) (generado por `generar_esquema.py`, que lee los GPIO
de `config.h`) y al [cableado de la placa perforada](placa_control.md) (34 cables numerados, generado y
verificado por `generar_placa_control.py`). Si cambia un pin en `config.h`, vuelva a ejecutar ambos scripts:
fallan si la placa no coincide con el firmware.

> Los colores de cable son una **recomendación** para no confundirse; lo obligatorio es respetar el destino
> de cada conductor. Antes de energizar, haga las comprobaciones de la sección 7.

## 1. Pines del ESP32 DevKit V1

| GPIO | Función | Dirección | Llega por | Componente | Notas de la auditoría |
|---|---|---|---|---|---|
| 26 | TRIG presencia | salida | J2 | HC-SR04 n.º 1 (cápsula 03) | 3,3 V es un ALTO válido para el HC-SR04 |
| 34 | ECHO presencia | entrada | J2 → R1 1k / R2 2k | HC-SR04 n.º 1 | solo entrada; el divisor deja ≈3,4 V |
| 19 | TRIG nivel de tolva | salida | J5 | HC-SR04 n.º 2 (cápsula 13b) | sin función de arranque |
| 21 | ECHO nivel de tolva | entrada | J5 → R5 1k / R6 2k | HC-SR04 n.º 2 | el divisor deja ≈3,4 V |
| 25 | PWM servo 50 Hz | salida | R3 330 Ω → J3 | MG995 (señal naranja) | R4 10k a GND: el servo no se mueve al arrancar |
| 35 | VBAT | ADC1 | J4 | divisor 100k/33k del cajón | 8,4 V → 2,08 V |
| 32 | V6 (riel del servo) | ADC1 | J4 | divisor 100k/33k del cajón | 6,0 V → 1,49 V |
| 33 | VPAN (panel solar) | ADC1 | J4 | divisor 100k/100k del cajón | se mide ANTES de D1; 4,0 V → 2,0 V |
| 2 | LED de estado | salida | — | LED azul de la placa | también es pin de arranque: solo el LED interno |
| 0 | Botón BOOT | entrada | — | botón de la placa | pulsación larga (2 s) = borrar error |
| VIN | 5,0 V | — | J1 | Buck B | ver nota 7 del esquema (USB + VIN) |
| GND | tierra | — | J1 y bus GND | punto estrella | |

No se usan: GPIO6–11 (flash), 1/3 (USB-serie), 0/2/5/12/15 para periféricos (arranque), 36/39 para pulsos
(falsas lecturas con el Wi-Fi), ADC2 (no funciona con el Wi-Fi activo) ni la salida 3V3 para cargas externas.

## 2. Estación solar remota (piezas 12a + 12b)

| Desde | Hasta | Cable | Notas |
|---|---|---|---|
| Panel + | GX12 macho, pin 1 | rojo AWG 20–22, bipolar de exterior, 3–5 m | soldar y aislar con termorretráctil en el panel |
| Panel − | GX12 macho, pin 2 | negro (mismo cable bipolar) | |
| Cable bipolar | base 12a | 2 ranuras + túnel para brida | alivio de tensión: el tirón no llega a las soldaduras |
| GX12 macho | GX12 hembra en la tapa trasera del cajón 16 | — | enchufar y desenchufar con S1 apagado |

## 3. Cajón de energía (pieza 16)

| Desde | Hasta | Sección | Notas |
|---|---|---|---|
| GX12 hembra pin 1 (+ panel) | D1 1N5817 ánodo | AWG 22 | |
| GX12 hembra pin 1 (+ panel) | divisor VPAN: 100k superior | AWG 26 | tomada ANTES del diodo |
| GX12 hembra pin 2 (− panel) | MT3608 IN− (= GND) | AWG 22 | |
| D1 cátodo (franja) | MT3608 IN+ | AWG 22 | |
| MT3608 OUT+ / OUT− (5,0 V) | Cargador 2S: entrada 5 V (+ / −) | AWG 22 | ajustar el MT3608 a 5,0 V ANTES de conectarlo |
| USB-C del cargador | cargador de pared 5 V | — | carga principal |
| Celda 1 − | BMS B− | AWG 20 | portapilas 2S |
| Unión celda 1 + / celda 2 − | BMS BM | AWG 22 | balanceo |
| Celda 2 + | BMS B+ | AWG 20 | |
| Cargador salida + / − (8,4 V) | BMS P+ / P− | AWG 20 | el BMS protege la carga |
| BMS P+ | F1 4 A lento | AWG 20 | fusible lo más cerca posible del BMS |
| F1 | S1 interruptor | AWG 20 | |
| S1 | bus VBAT (6,0–8,4 V) | AWG 20 | |
| bus VBAT | Buck A IN+, Buck B IN+ | AWG 20 | |
| bus VBAT | divisor VBAT: 100k superior | AWG 26 | |
| BMS P− | punto estrella GND | AWG 20 | |
| Buck A IN−, Buck B IN−, MT3608 OUT− | punto estrella GND | AWG 20–22 | |
| Buck A OUT+ (6,0 V) | conector de potencia del servo (XT30 o JST-VH) | AWG 20 | NO pasa por la placa de control |
| Buck A OUT+ (6,0 V) | divisor V6: 100k superior | AWG 26 | |
| Buck A OUT− | conector de potencia del servo (−) | AWG 20 | |
| Buck B OUT+ / OUT− (5,0 V) | C 470 µF (+ / −) y bus 5 V | AWG 22 | |
| bus 5 V / GND | cable J1 → placa de control | AWG 22, 25 cm | |
| bus 5 V / GND | cable de la ESP32-CAM | AWG 22, 45 cm | |
| nodos de los divisores (VBAT, V6, VPAN) + GND | cable J4 → placa de control | AWG 24–26, 25 cm | divisores: 33k / 33k / 100k inferiores a GND |

## 4. Placa de control (bandeja 05)

El cableado interno está en [placa_control.md](placa_control.md) (34 cables, de dónde a dónde, con el recorrido de
cada uno). Conectores:

| Conector | Pines (orden en la placa) | Cable hacia |
|---|---|---|
| J1 | GND · 5V | bus de 5 V del cajón |
| J2 | VCC · TRIG · ECHO · GND | HC-SR04 de presencia (cápsula 03) |
| J3 | SIG · GND | MG995: naranja (señal) y marrón (GND) |
| J4 | VBAT · V6 · VPAN · GND | divisores del cajón |
| J5 | GND · ECHO · TRIG · VCC (de izquierda a derecha, borde superior) | HC-SR04 de nivel (tapa de la tolva) |

## 5. Periféricos

| Componente | Pin | Va a | Notas |
|---|---|---|---|
| HC-SR04 n.º 1 (presencia) | VCC / TRIG / ECHO / GND | J2 (mismo orden) | cable de 4 hilos ~30 cm por el paso izquierdo del tabique |
| HC-SR04 n.º 2 (nivel) | VCC / TRIG / ECHO / GND | J5 (el cable llega girado: GND-ECHO-TRIG-VCC) | ~120 cm: ranura de la tapa 13a → conducto de la esquina trasera izquierda (07 → 08d) → bahía trasera de 02. Dejar ~20 cm flojos bajo la tapa |
| MG995 | naranja (señal) | J3 SIG | |
| MG995 | marrón (GND) | J3 GND **y** GND del Buck A (empalme en Y) | la corriente del motor vuelve por el Buck A, no por la placa |
| MG995 | rojo (V+) | Buck A OUT+ (6,0 V) | condensador 1000–2200 µF ≥10 V entre rojo y marrón, junto al servo |
| ESP32-CAM | 5V / GND | bus 5 V del cajón | 470 µF + 100 nF soldados junto a la cámara; sin cables de datos (solo Wi-Fi) |

## 6. Recorridos de cables por la torre

| Cable | Recorrido |
|---|---|
| Panel (exterior) | estación 12a → suelo → GX12 de la tapa trasera del cajón 16 |
| J1, J4, ESP32-CAM 5 V | cajón 16 → agujero del piso de 02 → bahía trasera |
| J2 | cápsula 03 → agujero del frente (fuera del canal) → paso izquierdo del tabique → bahía trasera |
| ESP32-CAM | cápsula 04 → agujero del frente → paso derecho del tabique → bahía trasera |
| J3 + 6 V del servo | soporte 06 → bahía trasera (el 6 V baja por el agujero del piso hasta el cajón) |
| J5 (nivel) | cápsula 13b → ranura sobre la tapa 13a → conducto Ø8 de la esquina trasera izquierda (07 y 08d) → bahía trasera |

Ningún cable pasa por el canal de alimento (09) ni por la tolva (el conducto de la esquina es un tubo cerrado,
fuera del embudo).

## 7. Comprobaciones antes de energizar

1. Con todo desconectado, ajustar Buck A = 6,0 V, Buck B = 5,0 V y MT3608 = 5,0 V (multímetro, sin carga).
2. Continuidad: ninguna entre 5 V y GND, 6 V y GND, VBAT y GND (placa y cajón).
3. Placa de control SIN el ESP32: alimentar J1 con 5 V y medir 5 V en VIN, en J2.VCC y en J5.VCC.
4. Con los HC-SR04 conectados y sin el ESP32, medir con el multímetro en los agujeros de D34 y D21: nunca más
   de 3,4 V (los divisores trabajan bien).
5. Colocar el ESP32, cargar el firmware y usar los comandos serie `DIST`, `NIVEL`, `ENERGIA` y `SERVO 1500`
   (ver `ESP32/README.md`) antes de montar la torre completa.

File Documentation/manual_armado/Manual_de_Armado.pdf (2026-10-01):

# Manual de armado · Dispensador inteligente de alimento para mascotas

Torre modular impresa en 3D + estación solar remota + sensor de nivel en la tolva

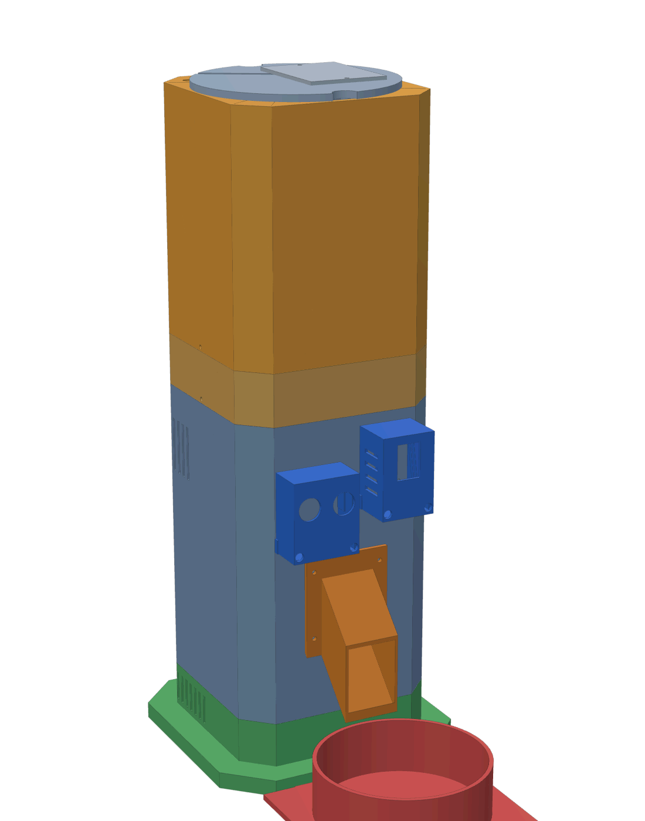
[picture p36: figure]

Este manual explica cómo pasar de las piezas impresas a la torre armada, paso por paso. Las piezas se imprimen con los STL de Mechanical/STL (ya orientados para la Elegoo Neptune 4 Plus) siguiendo el plan de impresión. El cableado eléctrico está en la tabla de conexiones, el esquema completo y la placa de control; aquí se indica en qué momento del armado conviene hacer cada parte.

Antes de empezar: lea el manual completo una vez. Hay dos pasos que no se pueden hacer después sin desarmar: la bandeja del ESP32 y las cápsulas del frente se atornillan antes de unir el cuerpo a la base (paso 2), y el disco se calibra antes de colocar la placa superior (pasos 6 y 7).

## Índice

0. Herramientas y tornillería
1. Control de las piezas impresas
2. Pasos de armado 1 Base y cajón · 2 Cuerpo · 3 Conducto y pico · 4 Servo · 5 Dosificador · 6 Disco · 7 Placa superior · 8 Tolva · 9 Tapa y sensor de nivel · 10 Tapa trasera y comedero
- 11 Estación solar
3. Calibración del sensor de nivel

Manual de armado · Dispensador IoT · página 1 de 20

4. Pruebas finales
5. Uso diario, limpieza y desarme
6. Problemas frecuentes

Manual de armado · Dispensador IoT · página 2 de 20

## 0. Herramientas y tornillería

Herramientas: destornillador Phillips PH1 y PH2, llave o pinza para tuercas M3 (5,5 mm) y M4 (7 mm), calibre (pie de rey), multímetro, cautín y estaño, termorretráctil, pistola de silicona caliente (o silicona neutra), cúter o desbarbador, broca de 3,4 mm y de 2,5 mm (solo para repasar agujeros), cinta doble faz de espuma (VHB).

Tornillería (total del proyecto):

Elemento | Cantidad | Dónde
Tornillo M3 × 10 (cabeza Phillips) | 26 (+4 de repuesto) | uniones de módulos, cápsulas, bandeja, viga, pico, tapa de servicio, cajón
Tornillo M3 × 12 | 6 | base ↔ cuerpo (4) y tapa de la cápsula del sensor de nivel (2)
Tuerca M3 | 8 (+4) | cápsulas 03/04 y bandeja 05
Tornillo M4 × 12 (mejor cabeza moleteada o mariposa) | 2 | pivote de la estación solar
Tuerca M4 + arandela M4 | 2 + 2 | pivote de la estación solar
Tornillos del servo, horn redondo y su tornillo central | los que trae el MG995 | servo ↔ viga, horn ↔ disco
Bridas plásticas (precintos) 2,5 mm | 6 | cables
Tornillos para madera Ø4 o tacos (opcional) | 4 | fijar la estación solar al suelo o a un muro

Reglas para los tornillos en plástico: los agujeros de Ø2,5 mm están hechos para que el tornillo M3 haga su propia rosca. Atornille despacio, sin taladro, y pare en cuanto la cabeza apoye: si se pasa, la rosca se barre. Los agujeros pasantes (Ø3,4 mm) deben dejar pasar el tornillo sin esfuerzo; si no, repáselos con la broca de 3,4 mm a mano.

Manual de armado · Dispensador IoT · página 3 de 20

## 1. Control de las piezas impresas

Código | Pieza | Material | Control después de imprimir
01 | Base de la torre | PLA | quitar la falda; los 4 pilares de las esquinas deben estar enteros
02 | Cuerpo principal | PLA | probar que 08a entra en el labio superior sin forzar (holgura 0,3 mm)
03 / 04 | Cápsulas HC-SR04 / ESP32-CAM | PLA | presentar el sensor y la cámara: deben entrar sin limar
05 | Bandeja del ESP32 | PLA | la placa perforada de 90 × 70 mm desliza en las guías
06 | Viga del servo | PETG | el MG995 entra en su ventana; orejas sobre las ranuras
07 | Tolva | PETG | pasar el dedo por dentro del embudo: sin hilos ni gotas (el alimento debe deslizar). Ver el surco MAX
08a | Carcasa del dosificador | PLA | —
08b | Disco dosificador | PETG | cara inferior plana: apoyarlo en una mesa y comprobar que no se balancea
08c / 08d | Placas superior y base | PETG | superficies de deslizamiento lisas; quitar rebabas de los agujeros de entrada y salida
09 / 10 | Conducto y pico | PETG | mirar a contraluz: el interior debe estar libre
11 | Comedero | PETG | —
12a / 12b | Estación solar (base y bandeja) | PETG | la tuerca M4 entra en el hexágono de cada nudillo de 12b
13a / 13b / 13c | Tapa, cápsula del sensor de nivel y su tapa | PETG | la cápsula 13b asienta en el avellanado de 13a quedando al ras
14 | Tapa de servicio | PLA | —
15 | Separadores | PLA | 12 tubos de 3, 6 y 10 mm
16 | Cajón de energía | PETG | el interruptor encaja en su ventana de 19,2 × 13 mm

Si alguna pieza que encaja en otra queda justa, lije la pieza interior (el labio o la pestaña), no la exterior.

Manual de armado · Dispensador IoT · página 4 de 20

## 2. Pasos de armado

### Paso 1 · Base (01) y cajón de energía (16)

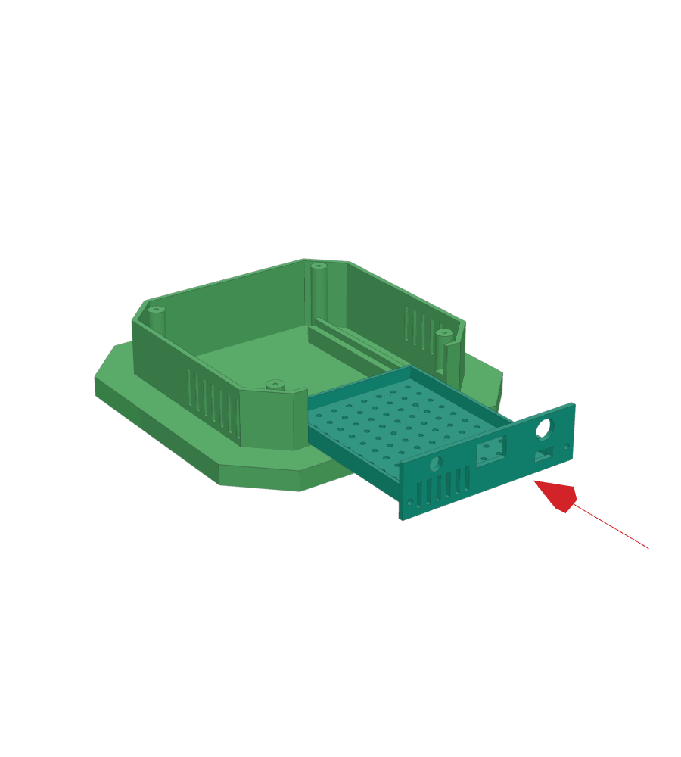
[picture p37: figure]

Piezas: 01, 16, separadores 15 · Tornillería: 2 × M3×10 + los de cada módulo electrónico · Antes: módulos de energía ajustados (Buck A = 6,0 V, Buck B = 5,0 V, MT3608 = 5,0 V, con multímetro y sin carga).

1. Coloque en la tapa trasera del cajón: el interruptor S1 (entra a presión en la ventana rectangular del centro), el conector GX12 hembra del panel (agujero redondo de 12 mm que está encima de la ventana pequeña del USB-C; el cuerpo por fuera y la tuerca por dentro) y el portafusible F1 o un LED en el agujero de Ø8 del otro lado. El USB-C del cargador debe quedar frente a su ventana pequeña.
2. Fije los módulos al piso del cajón usando la rejilla de agujeros (paso 10 mm) con tornillos M3 y separadores 15: portapilas 2S, BMS, cargador 2S, MT3608, Buck A, Buck B y la placa de los divisores. Los módulos sin agujeros se pegan con cinta doble faz de espuma.
3. Cablee el cajón según la tabla de conexiones, sección 3. Deje salir hacia arriba: el cable J1 (5 V), el cable de la ESP32-CAM (5 V), el cable J4 (mediciones) y el cable de potencia del servo (6 V).
4. Con S1 apagado y sin las celdas, revise con el multímetro que no haya continuidad entre + y − de cada salida. Coloque las celdas, encienda S1 y mida: VBAT 6,0–8,4 V, 6,0 V y 5,0 V. Apague S1.
5. Deslice el cajón en la base desde atrás hasta que la tapa trasera apoye, y atorníllelo con 2 × M3×10 en los agujeros de la tapa trasera.

✔ Comprobación: el cajón entra y sale sin tocar los cables; el interruptor y el GX12 quedan accesibles por detrás.

Manual de armado · Dispensador IoT · página 5 de 20

### Paso 2 · Cuerpo (02), bandeja (05) y cápsulas (03, 04)

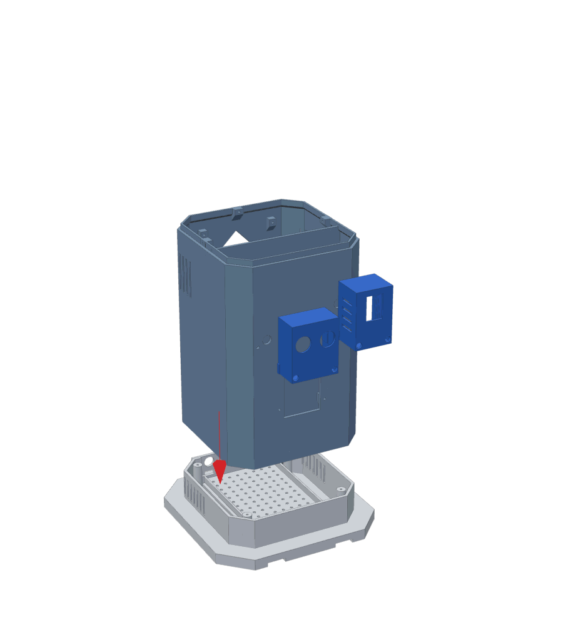
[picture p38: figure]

Piezas: 02, 03, 04, 05 · Tornillería: 8 × M3×10 + 8 tuercas M3; 4 × M3×12 para unir con la base.

1. Bandeja del ESP32 (05): apóyela en el piso de la bahía trasera de 02 (detrás del tabique) y atorníllela con 4 × M3×10; las tuercas van por debajo del piso. Hágalo ahora: después la base tapa el acceso.
2. Cápsula 03 (HC-SR04 de presencia, frente izquierda): coloque el sensor con los pines hacia abajo, pase el cable de 4 hilos por el agujero del frente y fije la cápsula con 2 × M3×10 + tuercas por dentro de la pared.
3. Cápsula 04 (ESP32-CAM, frente derecha): coloque la cámara (lente hacia el frente, con 470 µF + 100 nF ya soldados a sus pines de 5 V/GND), pase el cable de 5 V por su agujero y fíjela con 2 × M3×10 + tuercas.
4. Lleve los cables de 03 y 04 a la bahía trasera por los pasos izquierdo y derecho del tabique. Ningún cable cruza el canal de alimento.
5. Pase los cables que suben del cajón (J1, J4, cámara, 6 V del servo) por el agujero del piso de 02.
6. Apoye 02 sobre la base 01 y atorníllelo con 4 × M3×12 desde arriba, a través del piso, a los pilares de 01.

✔ Comprobación: la torre no cabecea; los cables no quedan pellizcados entre 01 y 02.

Manual de armado · Dispensador IoT · página 6 de 20

### Paso 3 · Conducto (09) y pico (10)

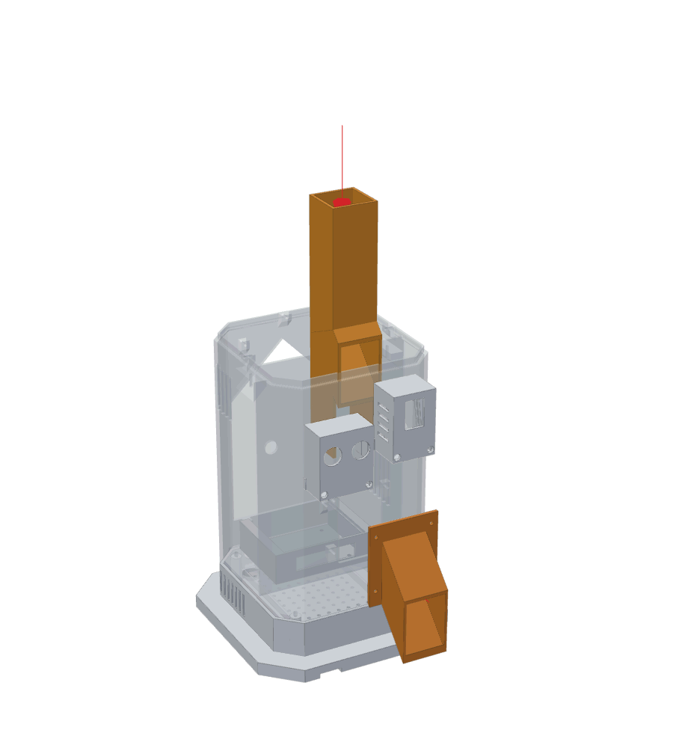
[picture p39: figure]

Piezas: 09, 10 · Tornillería: 4 × M3×10.

1. Baje el conducto 09 desde arriba por la zona frontal de 02 (delante del tabique), con el codo hacia el frente, hasta que apoye en el piso. Su boca superior queda centrada bajo la futura salida del disco.
2. Coloque el pico 10 desde fuera, encajado en la abertura del frente, y atornille su brida con 4 × M3×10.

✔ Comprobación: deje caer una croqueta por la boca superior de 09: debe salir por el pico sin trabarse.

Manual de armado · Dispensador IoT · página 7 de 20

### Paso 4 · Servo MG995 y viga (06)

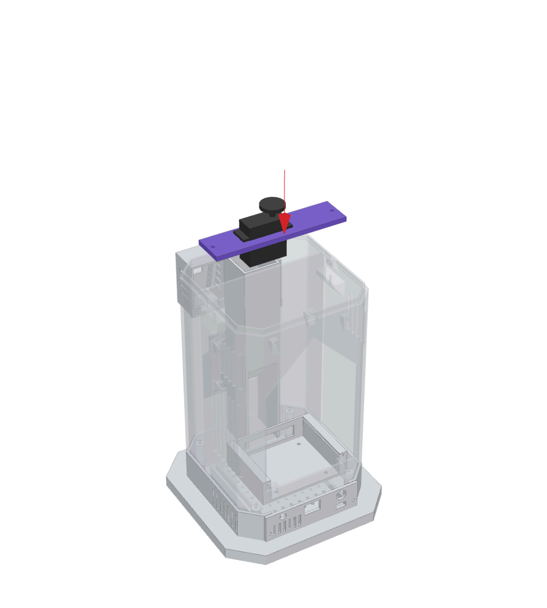
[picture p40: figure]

Piezas: 06, MG995, separadores de 3 mm · Tornillería: 2 × M3×10 + los 4 tornillos del servo.

1. Centre el servo antes de montarlo: en la mesa de trabajo, conéctelo a J3 de la placa de control y al 6 V del Buck A, cargue el firmware y envíe por el monitor serie SERVO 1500 (ver ESP32/README.md ). No gire el eje a mano después.
2. Atornille el MG995 a la viga 06 con sus 4 tornillos (las ranuras permiten ajustar).
3. Apoye la viga en las dos ménsulas internas de 02 y atorníllela con 2 × M3×10. Si el eje queda bajo, ponga separadores de 3 mm (15) como calces.
4. Lleve el cable del servo a la bahía trasera: naranja → J3 SIG, marrón → J3 GND y GND del Buck A, rojo → 6 V del Buck A (con el condensador de 1000–2200 µF junto al servo).

✔ Comprobación: la estría del servo queda en el centro de la torre, apuntando hacia arriba.

Manual de armado · Dispensador IoT · página 8 de 20

### Paso 5 · Carcasa (08a) y placa base (08d)

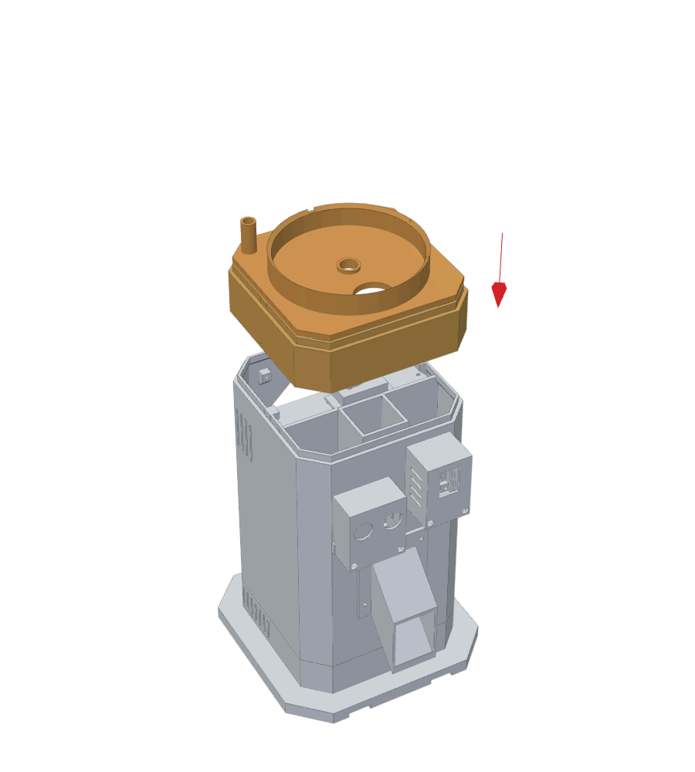
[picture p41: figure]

Piezas: 08a, 08d · Tornillería: 3 × M3×10 (radiales).

1. Coloque la carcasa 08a sobre el labio de 02 y fíjela con 3 × M3×10 desde fuera, en el centro de las paredes izquierda, derecha y trasera (los tornillos roscan en los tetones del labio).
2. Baje la placa base 08d dentro de 08a hasta que apoye en el labio de 02, con el agujero de salida (Ø32) hacia el frente y el tubito del conducto de cables en la esquina trasera izquierda.

✔ Comprobación: la estría del servo asoma por el agujero central de 08d; la salida de 08d queda sobre el conducto 09.

Manual de armado · Dispensador IoT · página 9 de 20

### Paso 6 · Disco dosificador (08b) y calibración

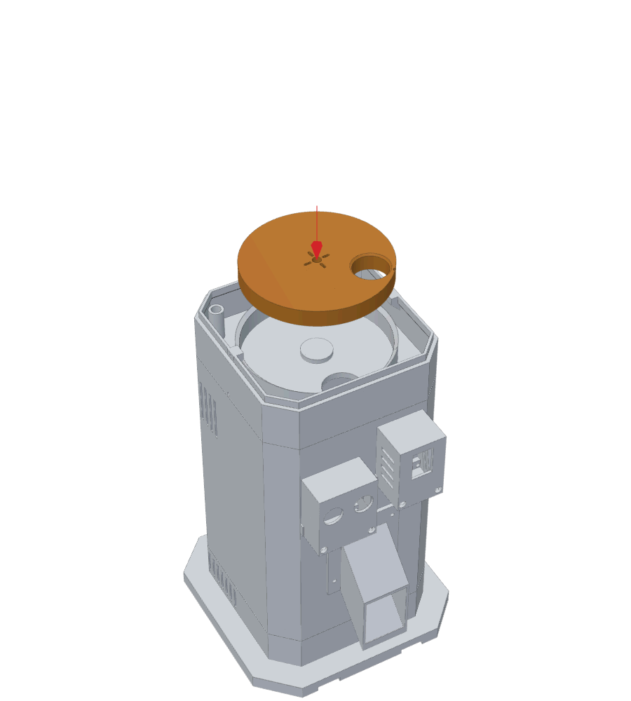
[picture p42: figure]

Piezas: 08b, horn redondo del MG995 · Tornillería: tornillos del horn y tornillo central del servo.

1. Atornille el horn redondo al disco 08b (cara inferior) con los tornillitos que trae el servo.
2. Con el servo en 1500 µs, apoye el disco con su marca frente a la marca CERRADO de 08d y encájelo en la estría. Coloque el tornillo central.
3. Gírelo con SERVO <µs> y compruebe que no roce en ningún punto (debe quedar ~0,5 mm de luz bajo el disco).
4. Calibre ahora las posiciones ENTRADA, CERRADO y SALIDA con las marcas de 08d a la vista ( Documentation/calibration ) y anótelas en config.h .

✔ Comprobación: CICLO 1 mueve el disco ENTRADA → SALIDA → CERRADO sin golpes ni roces.

Manual de armado · Dispensador IoT · página 10 de 20

### Paso 7 · Placa superior (08c)

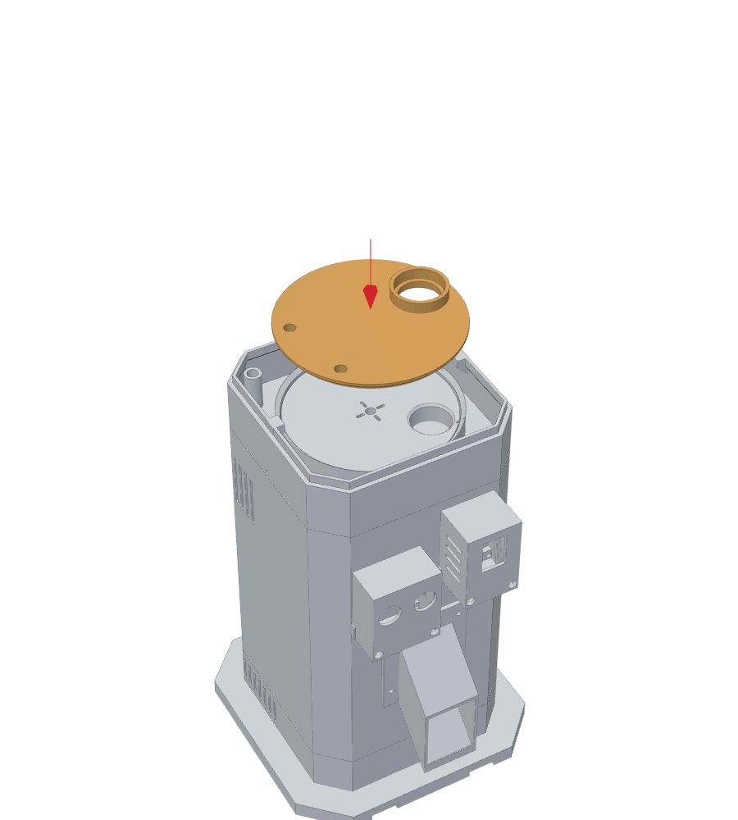
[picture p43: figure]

Piezas: 08c · Sin tornillos.

1. Baje la placa superior 08c sobre el asiento cónico de 08d con la chaveta en su chavetero (solo entra en una posición). El zócalo (anillo saliente) queda sobre la entrada, a la derecha mirando la torre de frente.

✔ Comprobación: CICLO 1 sigue funcionando igual (si roza, la placa no asentó: levántela y vuelva a bajarla).

Manual de armado · Dispensador IoT · página 11 de 20

### Paso 8 · Tolva (07)

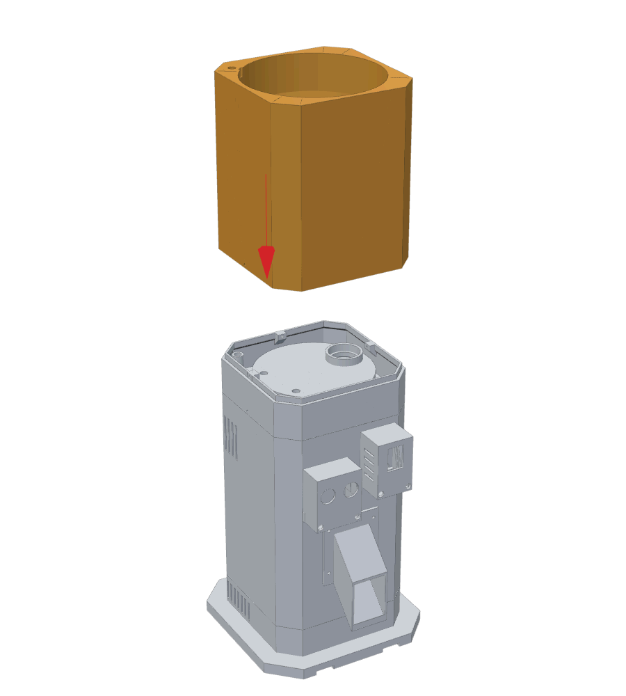
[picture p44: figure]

Piezas: 07 · Tornillería: 3 × M3×10 (radiales).

1. Baje la tolva sobre el labio de 08a: la boca inferior del embudo entra en el zócalo de 08c y el tubo de cables de la esquina trasera izquierda queda alineado con el de 08d.
2. Fíjela con 3 × M3×10 en el centro de las paredes izquierda, derecha y trasera.

✔ Comprobación: mire desde arriba: la boca del embudo coincide con la entrada de 08c; por el tubo de la esquina se ve la bahía trasera.

### Paso 9 · Tapa (13a) con el sensor de nivel (13b + 13c)

Recomendación del profesor: un segundo HC-SR04 dentro de la tolva avisa cuando la comida se está acabando.

Manual de armado · Dispensador IoT · página 12 de 20

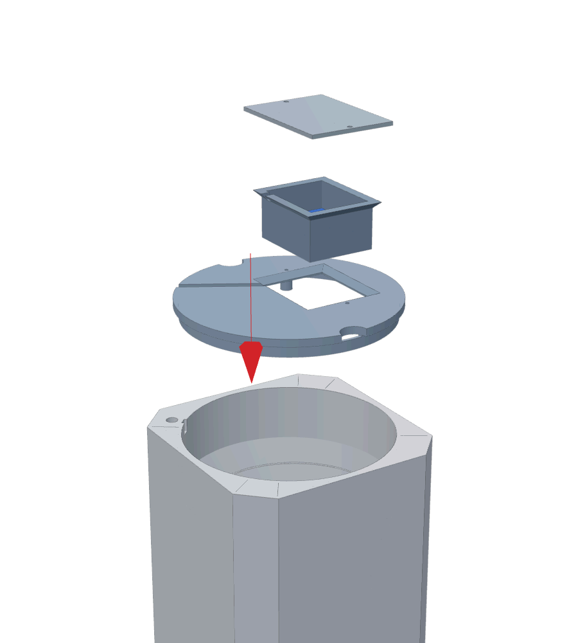
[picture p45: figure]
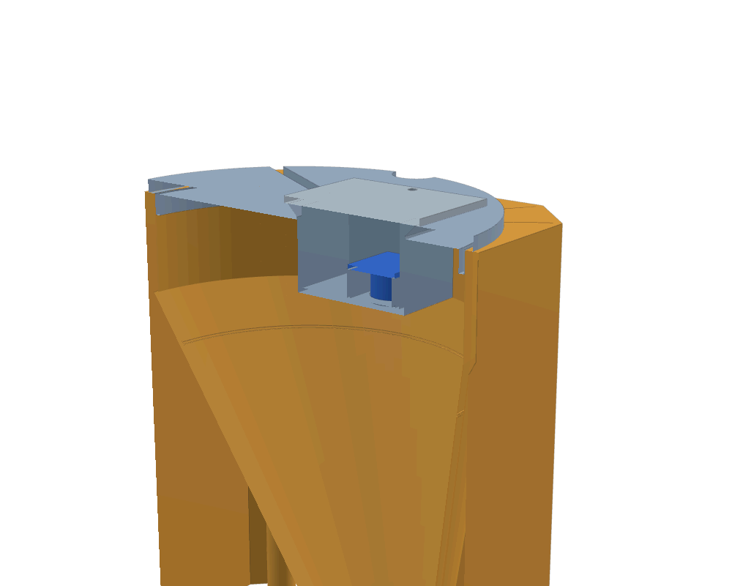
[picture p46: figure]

Piezas: 13a, 13b, 13c, HC-SR04 n.º 2 · Tornillería: 2 × M3×12 · cable de 4 hilos de ~120 cm.

1. Cable: suelde (o conecte con un conector Dupont de 4 vías) el cable al HC-SR04 n.º 2 en el orden VCC-TRIG-ECHO-GND y aísle con termorretráctil.
2. Sensor en la cápsula 13b: apoye la placa con los dos transductores hacia abajo, pasándolos por los agujeros del piso de la cápsula; la placa descansa en los dos nervios. Los transductores quedan aproximadamente al ras de la cara inferior (si sobresalen un poco, no importa; si quedan hundidos, lime un poco los nervios). Fije la placa con dos

Manual de armado · Dispensador IoT · página 13 de 20 gotas de silicona en los nervios (no tape los transductores). Saque el cable por la
muesca del borde de la cápsula.
3. Cápsula en la tapa: desde arriba, introduzca la cápsula en la abertura de la tapa 13a: el ala a 45° asienta en el avellanado y queda al ras de la cara superior. Acomode el cable en la ranura que va hacia la llave de la tapa.
4. Coloque la tapa de la cápsula 13c y atorníllela con 2 × M3×12 a los tetones de 13a. El cable queda apretado en la muesca: no se tironea de las soldaduras.
5. Recorrido del cable: desde el borde de la tapa, el cable baja por el tubo de la esquina trasera izquierda (tolva 07 → placa base 08d) hasta la bahía trasera de 02, y llega a J5 de la placa de control (GND-ECHO-TRIG-VCC de izquierda a derecha en el borde superior de la placa; el mismo cable, girado). Deje ~20 cm flojos entre la tapa y el tubo: así la tapa se levanta y se apoya al costado para cargar alimento.
6. Coloque la tapa: la llave del aro inferior entra en la ranura de la tolva (esquina trasera izquierda). Solo hay una posición, y siempre es la misma: así la calibración del sensor no cambia al abrir y cerrar.

✔ Comprobación: con la tolva vacía, el comando serie NIVEL responde una distancia (no "sin lectura").

⚠ Nunca llene por encima del surco MAX del embudo: el HC-SR04 no mide a menos de 2 cm, y el surco está a 3 cm de los transductores.

### Paso 10 · Tapa de servicio (14) y comedero (11)

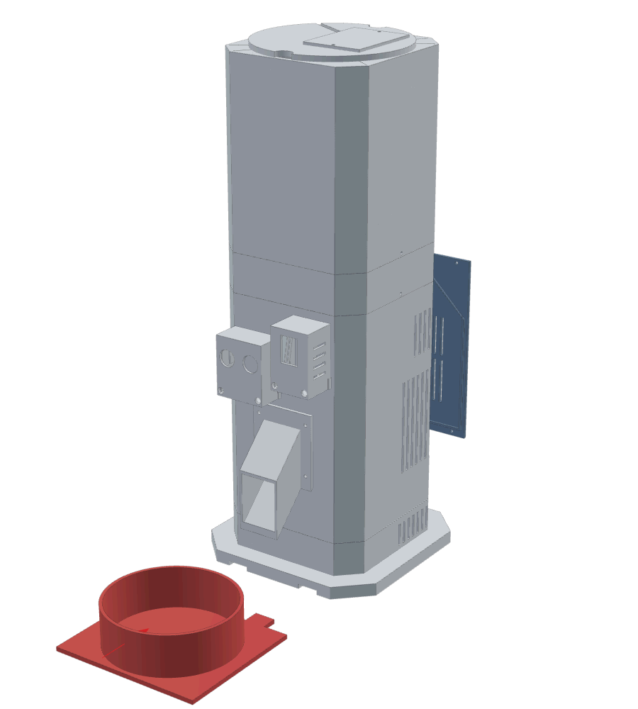
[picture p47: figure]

Piezas: 14, 11 · Tornillería: 4 × M3×10.

1. Coloque la placa de control (con el ESP32) en la bandeja 05 deslizándola por las guías y conecte J1 a J5.
2. Cierre la bahía trasera con la tapa de servicio 14 (4 × M3×10). Las ranuras quedan como ventilación.

Manual de armado · Dispensador IoT · página 14 de 20

3. Encaje el comedero 11 por delante: sus dos lengüetas entran bajo el plinto de la base. Sin tornillos.

✔ Comprobación: el pico deja caer el alimento dentro del cuenco del comedero.

### Paso 11 · Estación solar remota (12a + 12b)

Recomendación del profesor: el panel solar puede ir aparte del sistema, alejado del dispensador.

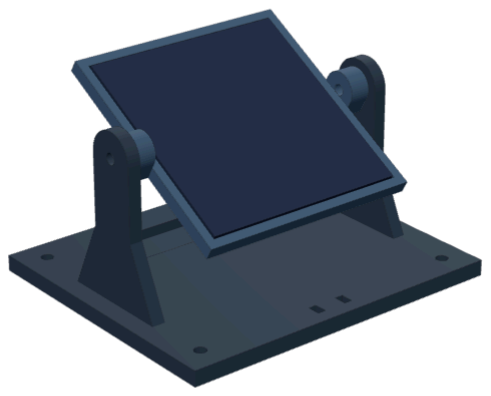
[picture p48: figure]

Piezas: 12a, 12b, panel solar · Tornillería: 2 × M4×12, 2 tuercas M4, 2 arandelas M4, 1 brida, 4 tornillos para madera o tacos (opcional) · cable bipolar de exterior de 3–5 m + conector GX12 macho de 2 pines.

1. Mida el panel y, si no es de 80 × 80 mm, cambie PANEL_W , PANEL_H y PANEL_E en generar_stl.py y vuelva a generar 12b antes de imprimirla.
2. Suelde el cable bipolar a los terminales del panel (rojo = +, negro = −) y aísle. Pase el cable por la ventana central de la bandeja 12b y pegue el panel en el alojamiento con cinta doble faz de exterior.
3. Suelde el otro extremo del cable al GX12 macho: pin 1 = + (rojo), pin 2 = − (negro). Compruebe la polaridad con el multímetro al sol antes de enchufarlo.
4. Introduzca una tuerca M4 en el hexágono de la cara exterior de cada nudillo de 12b.
5. Coloque la bandeja entre las orejas de la base 12a y pase un M4×12 con arandela desde fuera de cada oreja hasta la tuerca.
6. Ajuste la inclinación: aproximadamente la latitud del lugar (mínimo 10–15° para que escurran el agua y el polvo), con el panel mirando hacia el ecuador (al norte en el hemisferio sur, al sur en el hemisferio norte). Apriete los dos tornillos: la fricción mantiene el ángulo (0–75°).
7. Sujete el cable con una brida a la base (dos ranuras y un túnel por debajo) para que un tirón no llegue a las soldaduras. Fije la base con 4 tornillos o lastre en el bolsillo (por

Manual de armado · Dispensador IoT · página 15 de 20 ejemplo, tuercas o arandelas pegadas).
8. Lleve el cable hasta la torre y, con S1 apagado, enchufe el GX12 en la tapa trasera del cajón.

✔ Comprobación: con el panel al sol, el comando serie ENERGIA muestra la tensión del panel

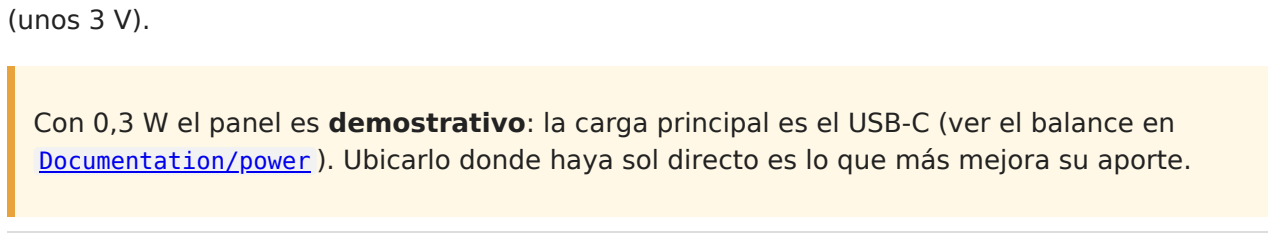
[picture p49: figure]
(unos 3 V).

Con 0,3 W el panel es demostrativo: la carga principal es el USB-C (ver el balance en Documentation/power ). Ubicarlo donde haya sol directo es lo que más mejora su aporte.

Manual de armado · Dispensador IoT · página 16 de 20

## 3. Calibración del sensor de nivel

El firmware convierte la distancia en porcentaje del volumen (el embudo se estrecha: con el 20 % de la altura queda solo ~5 % del alimento; la tabla altura → volumen se calcula con el modelo 3D, ver NivelGeometria.h ).

1. Con la tolva vacía y la tapa puesta, envíe NIVEL VACIO por el monitor serie.
2. Cargue alimento hasta el surco MAX, nivélelo con la mano y envíe NIVEL LLENO .
3. Envíe NIVEL : debe responder cerca de 100 %. Los valores quedan guardados en la memoria del ESP32.
Volumen restante | Qué pasa
< 20 % (≈125 cm³) tres lecturas seguidas | alerta COMIDA_BAJA al PC (panel web) y, si se configuró ntfy, al celular
≤ 3 % | alerta COMIDA_AGOTADA: el dispensador no entrega raciones (girar en vacío no alimenta)
> 30 % después de recargar | alerta COMIDA_REPUESTA: todo vuelve a la normalidad

Los umbrales están en la sección 8 de config.h . Para convertir volumen en gramos, pese una taza de su alimento (densidad aparente) — depende de cada marca.

Manual de armado · Dispensador IoT · página 17 de 20

## 4. Pruebas finales

1. Monitor serie: ESTADO (sin errores), DIST (presencia), NIVEL , ENERGIA .
2. Servidor de visión en el PC en marcha; panel web en http://IP-DEL-PC:8000/ .
3. Acerque una foto impresa de un perro o un gato al frente: el ESP32 detecta, fotografía, clasifica y dispensa (1 = PERRO, 2 = GATO). Con una imagen dudosa no debe dispensar.
4. Pese varias raciones y ajuste los ciclos por clase (ver Documentation/calibration ).
5. Saque alimento hasta bajar del 20 %: en menos de 3 minutos debe aparecer la alerta en el panel web.

Manual de armado · Dispensador IoT · página 18 de 20

## 5. Uso diario, limpieza y desarme

Cargar alimento: levantar la tapa por las muescas laterales, apoyarla al costado (el cable tiene holgura), llenar hasta el surco MAX y volver a colocarla con la llave atrás a la izquierda.
Limpieza (piezas en contacto con el alimento): quitar los 3 tornillos de la tolva y levantarla; la placa superior 08c y el disco 08b salen a mano (el disco, quitando el tornillo central del servo). Lavar 07, 08b, 08c, 08d, 09, 10 y 11 con agua tibia y jabón — no en lavavajillas — y secar bien antes de volver a cargar.
Electrónica: se accede quitando la tapa de servicio 14; el cajón de energía sale por detrás sin desarmar la torre.
Estación solar: limpiar el panel con un paño húmedo; revisar cada tanto el apriete de los tornillos M4.

Manual de armado · Dispensador IoT · página 19 de 20

## 6. Problemas frecuentes

Síntoma | Causa probable | Solución
El disco roza o se traba | 08c mal asentada, rebabas, servo bajo | asentar 08c con la chaveta; desbarbar; calzar la viga con separadores
Caen croquetas sin pedirlo | disco no está en CERRADO | recalibrar la posición CERRADO (paso 6)
La tolva no baja hasta el fondo | la boca no entra en el zócalo de 08c | girar la tolva: el tubo de cables va atrás a la izquierda
La tapa no entra | la llave no está frente a su ranura | girar la tapa hasta que la llave quede atrás a la izquierda
NIVEL dice "sin lectura" | cable cortado o invertido en J5 | revisar el orden GND-ECHO-TRIG-VCC en J5 y la continuidad
El nivel salta mucho | alimento amontonado bajo el sensor | nivelar al cargar; recalibrar VACIO/LLENO
ENERGIA muestra panel 0 V al sol | GX12 desenchufado o polaridad invertida | revisar pin 1 = +, pin 2 = −
La bandeja del panel se cae | tornillos M4 flojos | apretar; poner arandelas a ambos lados de las orejas

Las imágenes de los pasos se generan a partir del mismo modelo paramétrico que los STL ( Mechanical/generar_stl.py ).

Manual de armado · Dispensador IoT · página 20 de 20

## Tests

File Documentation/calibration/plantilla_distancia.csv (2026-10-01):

fecha | objeto | distancia_real_cm | lectura_1_cm | lectura_2_cm | lectura_3_cm | lectura_4_cm | lectura_5_cm | angulo_grados | observaciones
 | caja de carton | 10 |  |  |  |  |  | 0
 | caja de carton | 20 |  |  |  |  |  | 0
 | caja de carton | 30 |  |  |  |  |  | 0
 | caja de carton | 40 |  |  |  |  |  | 0
 | peluche (simula pelaje) | 20 |  |  |  |  |  | 0
 | peluche (simula pelaje) | 30 |  |  |  |  |  | 0
 | mascota real

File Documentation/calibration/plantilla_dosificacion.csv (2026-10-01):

fecha | tipo_alimento | tamano_grano_mm | nivel_tolva | pulso_llenado_us | pulso_descarga_us | t_llenado_ms | t_descarga_ms | ciclos | repeticion | masa_g | observaciones
 |  |  | lleno |  |  |  |  | 1 | 1
 |  |  | lleno |  |  |  |  | 1 | 2
 |  |  | lleno |  |  |  |  | 1 | 3
 |  |  | lleno |  |  |  |  | 1 | 4
 |  |  | lleno |  |  |  |  | 1 | 5
 |  |  | medio |  |  |  |  | 1 | 6
 |  |  | medio |  |  |  |  | 1 | 7
 |  |  | medio |  |  |  |  | 1 | 8
 |  |  | bajo |  |  |  |  | 1 | 9
 |  |  | bajo |  |  |  |  | 1 | 10

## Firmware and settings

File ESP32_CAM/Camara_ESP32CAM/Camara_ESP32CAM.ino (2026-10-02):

// =============================================================================
//  DISPENSADOR INTELIGENTE - Firmware de la ESP32-CAM (AI-Thinker, OV2640)
// =============================================================================
//  Responsabilidad ÚNICA: capturar una foto cuando se la piden y entregarla.
//  NO clasifica (eso lo hace el PC con OpenCV) y NO controla el servo.
//
//  Endpoints HTTP (puerto 80):
//    GET /capture -> image/jpeg  (foto nueva)         | 503 si la cámara falla
//    GET /status  -> application/json (diagnóstico)
//
//  Programación: adaptador USB-TTL de 3,3 V (TX->U0R, RX->U0T, GND, 5V) o placa
//  ESP32-CAM-MB. Unir GPIO0 a GND durante el arranque para entrar en modo carga.
//  Placa en Arduino IDE: "AI Thinker ESP32-CAM".
// =============================================================================
#include <Arduino.h>
#include <WebServer.h>
#include <WiFi.h>

#include "esp_camera.h"
#include "config.h"

#if __has_include("secrets.h")
#include "secrets.h"
#else
#warning "Falta secrets.h: se usa secrets_ejemplo.h (copie y complete sus datos de Wi-Fi)"
#include "secrets_ejemplo.h"
#endif

// --- Pines fijos del módulo AI-Thinker (ocupados por la cámara) ---------------
#define PWDN_GPIO_NUM     32
#define RESET_GPIO_NUM    -1
#define XCLK_GPIO_NUM      0
#define SIOD_GPIO_NUM     26
#define SIOC_GPIO_NUM     27
#define Y9_GPIO_NUM       35
#define Y8_GPIO_NUM       34
#define Y7_GPIO_NUM       39
#define Y6_GPIO_NUM       36
#define Y5_GPIO_NUM       21
#define Y4_GPIO_NUM       19
#define Y3_GPIO_NUM       18
#define Y2_GPIO_NUM        5
#define VSYNC_GPIO_NUM    25
#define HREF_GPIO_NUM     23
#define PCLK_GPIO_NUM     22
#define FLASH_GPIO_NUM     4   // LED de flash (alto = encendido)
#define LED_ROJO_GPIO_NUM 33   // LED rojo de la placa (activo en BAJO)

WebServer servidor(80);
bool camaraOk = false;
uint32_t fotosOk = 0, fotosFallidas = 0, tSinWifi = 0, tReintento = 0, tReintentoCam = 0;

bool iniciarCamara() {
  camera_config_t c = {};
  c.ledc_channel = LEDC_CHANNEL_0;
  c.ledc_timer = LEDC_TIMER_0;
  c.pin_d0 = Y2_GPIO_NUM;
  c.pin_d1 = Y3_GPIO_NUM;
  c.pin_d2 = Y4_GPIO_NUM;
  c.pin_d3 = Y5_GPIO_NUM;
  c.pin_d4 = Y6_GPIO_NUM;
  c.pin_d5 = Y7_GPIO_NUM;
  c.pin_d6 = Y8_GPIO_NUM;
  c.pin_d7 = Y9_GPIO_NUM;
  c.pin_xclk = XCLK_GPIO_NUM;
  c.pin_pclk = PCLK_GPIO_NUM;
  c.pin_vsync = VSYNC_GPIO_NUM;
  c.pin_href = HREF_GPIO_NUM;
  c.pin_sccb_sda = SIOD_GPIO_NUM;
  c.pin_sccb_scl = SIOC_GPIO_NUM;
  c.pin_pwdn = PWDN_GPIO_NUM;
  c.pin_reset = RESET_GPIO_NUM;
  c.xclk_freq_hz = 20000000;
  c.pixel_format = PIXFORMAT_JPEG;
  c.frame_size = TAMANO_FOTO;
  c.jpeg_quality = CALIDAD_JPEG;
  // MODO FOTO (idea del profesor: no grabar, solo sacar fotos): con un solo búfer el
  // controlador NO captura cuadros de forma continua; toma uno cuando se lo pide /capture.
  // El sensor sigue encendido, así la exposición automática ya está ajustada.
  if (psramFound()) {
    c.fb_count = 1;
    c.fb_location = CAMERA_FB_IN_PSRAM;
    c.grab_mode = CAMERA_GRAB_WHEN_EMPTY;
  } else {
    c.fb_count = 1;
    c.fb_location = CAMERA_FB_IN_DRAM;
    c.grab_mode = CAMERA_GRAB_WHEN_EMPTY;
    if (c.frame_size > FRAMESIZE_SVGA) c.frame_size = FRAMESIZE_SVGA;
  }
  esp_err_t err = esp_camera_init(&c);
  if (err != ESP_OK) {
    Serial.printf("ERROR camara 0x%x (revise cinta FPC y alimentacion 5 V)\n", err);
    return false;
  }
  sensor_t* s = esp_camera_sensor_get();
  s->set_whitebal(s, 1);
  s->set_exposure_ctrl(s, 1);
  s->set_gain_ctrl(s, 1);
  return true;
}

// Devuelve un cuadro "fresco": el que quedó en el búfer puede ser de la foto anterior
// (segundos o minutos atrás), así que se descarta y se toma uno nuevo.
camera_fb_t* capturarFresca() {
  camera_fb_t* fb = esp_camera_fb_get();
  if (fb) esp_camera_fb_return(fb);
  return esp_camera_fb_get();
}

void manejarCaptura() {
  if (!camaraOk) {
    fotosFallidas++;
    servidor.send(503, "application/json", "{\"error\":\"camara no inicializada\"}");
    return;
  }
#if USAR_FLASH
  digitalWrite(FLASH_GPIO_NUM, HIGH);
  delay(T_FLASH_MS);
#endif
  camera_fb_t* fb = capturarFresca();
#if USAR_FLASH
  digitalWrite(FLASH_GPIO_NUM, LOW);
#endif
  if (!fb || fb->format != PIXFORMAT_JPEG || fb->len == 0) {
    if (fb) esp_camera_fb_return(fb);
    fotosFallidas++;
    servidor.send(503, "application/json", "{\"error\":\"fallo de captura\"}");
    return;
  }
  servidor.sendHeader("Cache-Control", "no-store");
  servidor.setContentLength(fb->len);
  servidor.send(200, "image/jpeg", "");
  servidor.client().write(fb->buf, fb->len);
  esp_camera_fb_return(fb);
  fotosOk++;
}

void manejarEstado() {
  char buf[256];
  snprintf(buf, sizeof(buf),
           "{\"camara\":%s,\"psram\":%s,\"fotos_ok\":%lu,\"fotos_fallidas\":%lu,"
           "\"rssi\":%d,\"heap\":%u,\"uptime_s\":%lu}",
           camaraOk ? "true" : "false", psramFound() ? "true" : "false",
           (unsigned long)fotosOk, (unsigned long)fotosFallidas, WiFi.RSSI(),
           (unsigned)ESP.getFreeHeap(), (unsigned long)(millis() / 1000));
  servidor.send(camaraOk ? 200 : 503, "application/json", buf);
}

void conectarWifi() {
  WiFi.persistent(false);
  WiFi.mode(WIFI_STA);
  WiFi.setSleep(false);   // menor latencia al responder /capture
  WiFi.setAutoReconnect(true);
  IPAddress ip, gw, mascara;
  if (strlen(IP_CAMARA) > 0 && ip.fromString(IP_CAMARA) && gw.fromString(IP_GATEWAY) &&
      mascara.fromString(IP_MASCARA)) {
    WiFi.config(ip, gw, mascara, gw);
  }
  WiFi.begin(WIFI_SSID, WIFI_CLAVE);
  uint32_t t0 = millis();
  while (WiFi.status() != WL_CONNECTED && millis() - t0 < 15000) delay(250);
  if (WiFi.status() == WL_CONNECTED) {
    Serial.printf("Wi-Fi OK  http://%s/capture  RSSI=%d dBm\n", WiFi.localIP().toString().c_str(),
                  WiFi.RSSI());
  } else {
    Serial.println("Wi-Fi: sin conexion (se reintentara)");
  }
}

void setup() {
  Serial.begin(115200);
  Serial.println("\n=== Dispensador IoT - ESP32-CAM ===");
  pinMode(FLASH_GPIO_NUM, OUTPUT);
  digitalWrite(FLASH_GPIO_NUM, LOW);
  pinMode(LED_ROJO_GPIO_NUM, OUTPUT);
  digitalWrite(LED_ROJO_GPIO_NUM, HIGH);  // apagado

  camaraOk = iniciarCamara();
  conectarWifi();
  servidor.on("/capture", HTTP_GET, manejarCaptura);
  servidor.on("/status", HTTP_GET, manejarEstado);
  servidor.onNotFound([]() { servidor.send(404, "application/json", "{\"error\":\"ruta desconocida\"}"); });
  servidor.begin();
}

void loop() {
  servidor.handleClient();

  // LED rojo encendido = sin Wi-Fi o cámara con fallo
  bool problema = !camaraOk || WiFi.status() != WL_CONNECTED;
  digitalWrite(LED_ROJO_GPIO_NUM, problema ? LOW : HIGH);

  if (WiFi.status() != WL_CONNECTED) {
    if (tSinWifi == 0) tSinWifi = millis();
    if (millis() - tReintento > WIFI_REINTENTO_MS) {
      tReintento = millis();
      WiFi.reconnect();
    }
    if (millis() - tSinWifi > WIFI_REINICIO_MS) ESP.restart();
  } else {
    tSinWifi = 0;
  }

  if (!camaraOk && millis() - tReintentoCam > 10000) {  // reintento de inicialización
    tReintentoCam = millis();
    esp_camera_deinit();
    camaraOk = iniciarCamara();
  }
  delay(2);
}

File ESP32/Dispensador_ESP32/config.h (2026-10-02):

// =============================================================================
//  config.h  -  Configuración del ESP32 DevKit V1 (controlador del dispensador)
// =============================================================================
//  Los valores marcados PROVISIONAL NO son datos de fábrica: son puntos de
//  partida seguros que DEBEN reemplazarse con los obtenidos en la calibración
//  (Documentation/calibration/calibracion.md).
// =============================================================================
#pragma once

// -----------------------------------------------------------------------------
// 1. PINES  (auditados: ver Documentation/wiring/tabla_conexiones.md)
// -----------------------------------------------------------------------------
#define PIN_TRIG      26  // Salida -> TRIG HC-SR04 (3,3 V es nivel TTL alto válido)
#define PIN_ECHO      34  // SOLO ENTRADA. ECHO (5 V) llega por divisor 1k/2k (~3,3 V)
#define PIN_SERVO     25  // PWM 50 Hz (LEDC) -> señal MG995 (con 330 ohm en serie)
#define PIN_VBAT      35  // ADC1_CH7: batería 2S por divisor 100k/33k
#define PIN_VSERVO    32  // ADC1_CH4: riel de 6 V del servo por divisor 100k/33k
#define PIN_VPANEL    33  // ADC1_CH5: tensión del panel solar por divisor 100k/100k
#define PIN_LED        2  // LED azul de la placa (indicador de estado)
#define PIN_BOTON      0  // Botón BOOT de la placa: pulsación larga = borrar error
#define PIN_TRIG_NIVEL 19 // Salida -> TRIG del HC-SR04 de la TOLVA (sin función de arranque)
#define PIN_ECHO_NIVEL 21 // ECHO del HC-SR04 de la tolva por divisor 1k/2k (~3,3 V)
// (19 y 21 están en la otra fila de pines del DevKit, junto al conector J5: cableado corto)
// Se usan solo canales ADC1 porque ADC2 no funciona mientras el Wi-Fi está activo.

// Factores de los divisores: (R_superior + R_inferior) / R_inferior
#define FACTOR_VBAT    ((100.0f + 33.0f) / 33.0f)
#define FACTOR_VSERVO  ((100.0f + 33.0f) / 33.0f)
#define FACTOR_VPANEL  ((100.0f + 100.0f) / 100.0f)

// -----------------------------------------------------------------------------
// 2. RED  (ajustar a la red real; Wi-Fi 2,4 GHz WPA2-Personal)
// -----------------------------------------------------------------------------
// SSID y contraseña van en secrets.h (copiar secrets_ejemplo.h -> secrets.h)
#define IP_ESP32        "192.168.1.52"   // "" = usar DHCP
#define IP_GATEWAY      "192.168.1.1"
#define IP_MASCARA      "255.255.255.0"
#define URL_PC          "http://192.168.1.50:8000"   // servidor_vision.py
#define URL_CAMARA      "http://192.168.1.51"        // ESP32-CAM

#define TIMEOUT_CONEXION_MS     2000UL   // conexión TCP
#define TIMEOUT_CLASIFICAR_MS  10000UL   // respuesta completa de /classify
#define TIMEOUT_ESTADO_MS       2000UL   // /status de cámara o PC
#define WIFI_REINTENTO_MS       5000UL   // cada cuánto reintentar Wi-Fi
#define WIFI_REINICIO_MS      300000UL   // sin Wi-Fi 5 min -> reiniciar ESP32
#define ERROR_REINTENTO_MS     30000UL   // reintento en ERROR_CAMARA / ERROR_CLASIFICACION

// -----------------------------------------------------------------------------
// 3. DETECCIÓN CON HC-SR04  (PROVISIONAL: calibrar en el lugar de uso)
// -----------------------------------------------------------------------------
#define DIST_MIN_CM            3.0f   // < 3 cm: sensor tapado o lectura inválida
#define DIST_DETECCION_CM     35.0f   // mascota "presente" si está más cerca que esto
#define DIST_LIBRE_CM         50.0f   // zona "libre" si está más lejos (histéresis)
#define LECTURAS_CONFIRMACION     3   // lecturas seguidas para confirmar presencia
#define ZONA_LIBRE_MS         3000UL  // tiempo de zona libre para rearmar la detección
#define N_MUESTRAS_DIST           3   // mediana de N disparos (>=60 ms entre disparos)
#define TIMEOUT_ECO_US        30000UL // ~5 m: sin eco = nada delante

// -----------------------------------------------------------------------------
// 4. CLASIFICACIÓN
// -----------------------------------------------------------------------------
// Idea del profesor: la cámara NO graba video; saca una foto cada ~2 s solo mientras la
// mascota está delante, hasta identificarla (como máximo 5 fotos ≈ 10 s por visita).
#define MAX_INTENTOS_CLASIFICACION   5   // fotos con resultado 0 seguidas antes de desistir
#define REINTENTO_CLASIFICACION_MS 2000UL // espera entre fotos de una misma visita
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

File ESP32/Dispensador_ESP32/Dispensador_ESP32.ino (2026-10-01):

// =============================================================================
//  DISPENSADOR INTELIGENTE DE ALIMENTO PARA MASCOTAS
//  IoT + Visión artificial + Energía solar
//  Firmware del ESP32 DevKit V1 (controlador y actuador)
// =============================================================================
//  Responsabilidades del ESP32:
//    * Leer el HC-SR04 y confirmar la presencia de una mascota.
//    * Medir el nivel de la tolva (segundo HC-SR04) y avisar al PC cuando la
//      comida se está acabando.
//    * Pedir la clasificación al PC (que a su vez pide la foto a la ESP32-CAM).
//    * DECIDIR si corresponde dispensar (clase válida, cooldown, límite diario,
//      batería y riel del servo correctos, mascota todavía presente).
//    * Generar la señal PWM del MG995 (solo señal: el servo se alimenta aparte).
//    * Gestionar errores con una máquina de estados.
//
//  Entorno: Arduino IDE (núcleo esp32 2.x o 3.x) o PlatformIO.
//  Biblioteca externa: ArduinoJson 7 (Benoît Blanchon).
// =============================================================================
#include <Arduino.h>
#include <WiFi.h>

#include "Controlador.h"
#include "Dosificador.h"
#include "Energia.h"
#include "NivelGeometria.h"
#include "NivelTolva.h"
#include "Red.h"
#include "Ultrasonico.h"
#include "config.h"

#if __has_include("secrets.h")
#include "secrets.h"
#else
#warning "Falta secrets.h: se usa secrets_ejemplo.h (copie y complete sus datos de Wi-Fi)"
#include "secrets_ejemplo.h"
#endif

// ----------------------------------------------------------------------------
// Módulos de hardware
// ----------------------------------------------------------------------------
Energia energia;
Ultrasonico ultrasonico(PIN_TRIG, PIN_ECHO, N_MUESTRAS_DIST, TIMEOUT_ECO_US);
NivelTolva nivel(PIN_TRIG_NIVEL, PIN_ECHO_NIVEL);
Dosificador dosificador(PIN_SERVO, energia, USAR_MONITOR_SERVO);
Red red;

// Une los módulos reales con la interfaz que usa la máquina de estados.
class HardwareReal : public Hardware {
 public:
  uint32_t ahoraMs() override { return millis(); }
  float distanciaCm() override { return ultrasonico.medirCm(); }
  bool wifiConectado() override { return red.conectado(); }
  void reconectarWifi() override { red.reconectar(); }
  bool camaraDisponible() override { return red.camaraDisponible(); }
  bool servidorDisponible() override { return red.servidorDisponible(); }
  RespuestaClasificacion clasificar(int d) override { return red.clasificar(d); }
  float voltajeBateria() override { return energia.bateria(); }
  float voltajeServo() override { return energia.servo(); }
  float nivelTolvaPct() override { return USAR_SENSOR_NIVEL ? nivel.porcentaje() : -1.0f; }
  bool notificar(Alerta a, float n) override { return red.notificar(nombreAlerta(a), n); }
  ResultadoDosis dosificar(uint8_t ciclos) override {
    digitalWrite(PIN_LED, HIGH);
    ResultadoDosis r = dosificador.dosificar(ciclos);
    digitalWrite(PIN_LED, LOW);
    return r;
  }
  // Una pulsación larga = UN solo reset. Hay que soltar el botón para el siguiente:
  // así un botón mantenido (o GPIO0 a nivel bajo por una falla) no borra errores
  // de seguridad una y otra vez.
  bool botonResetPulsado() override {
    if (digitalRead(PIN_BOTON) == HIGH) {
      tBoton_ = 0;
      consumido_ = false;
      return false;
    }
    if (consumido_) return false;
    if (tBoton_ == 0) tBoton_ = millis();
    if (millis() - tBoton_ >= T_BOTON_RESET_MS) {
      consumido_ = true;
      return true;
    }
    return false;
  }
  void reiniciar() override {
    delay(200);
    ESP.restart();
  }
  void log(const char* m) override {
    Serial.printf("[%10lu] %s\n", (unsigned long)millis(), m);
  }

 private:
  uint32_t tBoton_ = 0;
  bool consumido_ = false;
};

HardwareReal hardware;

Parametros crearParametros() {
  Parametros p;
  p.distMinCm = DIST_MIN_CM;
  p.distDeteccionCm = DIST_DETECCION_CM;
  p.distLibreCm = DIST_LIBRE_CM;
  p.lecturasConfirmacion = LECTURAS_CONFIRMACION;
  p.zonaLibreMs = ZONA_LIBRE_MS;
  p.maxIntentosClasificacion = MAX_INTENTOS_CLASIFICACION;
  p.reintentoClasificacionMs = REINTENTO_CLASIFICACION_MS;
  p.ciclos[0] = 0;               p.habilitada[0] = false;
  p.ciclos[CLASE_PERRO] = CICLOS_PERRO;  p.habilitada[CLASE_PERRO] = HABILITAR_PERRO;
  p.ciclos[CLASE_GATO] = CICLOS_GATO;    p.habilitada[CLASE_GATO] = HABILITAR_GATO;
  p.cooldownClaseMs[0] = 0;
  p.cooldownClaseMs[CLASE_PERRO] = COOLDOWN_PERRO_MS;
  p.cooldownClaseMs[CLASE_GATO] = COOLDOWN_GATO_MS;
  p.maxRacionesDia[0] = 0;
  p.maxRacionesDia[CLASE_PERRO] = MAX_RACIONES_DIA_PERRO;
  p.maxRacionesDia[CLASE_GATO] = MAX_RACIONES_DIA_GATO;
  p.maxCiclosPorRacion = MAX_CICLOS_POR_RACION;
  p.cooldownGlobalMs = COOLDOWN_GLOBAL_MS;
  p.usarMonitorBateria = USAR_MONITOR_BATERIA;
  p.vbatMin = VBAT_MIN;
  p.vbatHisteresis = VBAT_HISTERESIS;
  p.usarMonitorServo = USAR_MONITOR_SERVO;
  p.vservoMin = VSERVO_MIN;
  p.wifiReintentoMs = WIFI_REINTENTO_MS;
  p.wifiReinicioMs = WIFI_REINICIO_MS;
  p.errorReintentoMs = ERROR_REINTENTO_MS;
  p.usarSensorNivel = USAR_SENSOR_NIVEL;
  p.intervaloNivelMs = INTERVALO_NIVEL_MS;
  p.nivelAlertaPct = NIVEL_ALERTA_PCT;
  p.nivelRearmePct = NIVEL_REARME_PCT;
  p.nivelVacioPct = NIVEL_VACIO_PCT;
  p.lecturasNivel = LECTURAS_NIVEL;
  p.reintentoAlertaMs = REINTENTO_ALERTA_MS;
  return p;
}

Controlador controlador(hardware, crearParametros());

// ----------------------------------------------------------------------------
// GET /status  (JSON para pruebas y monitoreo)
// ----------------------------------------------------------------------------
String estadoJson() {
  char buf[640];
  snprintf(buf, sizeof(buf),
           "{\"estado\":\"%s\",\"distancia_cm\":%.1f,\"ultima_clase\":%d,"
           "\"ultima_confianza\":%.2f,\"ultimo_motivo\":\"%s\","
           "\"raciones_perro\":%lu,\"raciones_gato\":%lu,"
           "\"raciones_24h_perro\":%u,\"raciones_24h_gato\":%u,"
           "\"cooldown_s\":%lu,\"v_bateria\":%.2f,\"v_servo\":%.2f,\"v_panel\":%.2f,"
           "\"nivel_tolva\":%.0f,\"alerta_tolva\":\"%s\",\"alerta_pendiente\":%s,"
           "\"rssi\":%d,\"uptime_s\":%lu,\"heap\":%u}",
           nombreEstado(controlador.estado()), controlador.ultimaDistancia(),
           controlador.ultimaClase(), controlador.ultimaConfianza(), controlador.ultimoMotivo(),
           (unsigned long)controlador.racionesTotales(CLASE_PERRO),
           (unsigned long)controlador.racionesTotales(CLASE_GATO),
           controlador.racionesUltimas24h(CLASE_PERRO), controlador.racionesUltimas24h(CLASE_GATO),
           (unsigned long)(controlador.cooldownRestanteMs() / 1000), energia.bateria(),
           energia.servo(), energia.panel(), controlador.nivelTolva(),
           nombreAlerta(controlador.alertaNivel()), controlador.alertaPendiente() ? "true" : "false",
           WiFi.RSSI(), (unsigned long)(millis() / 1000),
           (unsigned)ESP.getFreeHeap());
  return String(buf);
}
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

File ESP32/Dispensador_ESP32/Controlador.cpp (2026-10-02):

// =============================================================================
//  Controlador.cpp  -  Máquina de estados (ver Documentation/architecture)
// =============================================================================
#include "Controlador.h"

#include <stdarg.h>
#include <stdio.h>
#include <string.h>

static const uint32_t MS_24H = 86400000UL;

const char* nombreEstado(Estado e) {
  switch (e) {
    case Estado::ESPERANDO:           return "ESPERANDO";
    case Estado::DETECTADO:           return "DETECTADO";
    case Estado::CAPTURANDO:          return "CAPTURANDO";
    case Estado::PROCESANDO:          return "PROCESANDO";
    case Estado::CLASIFICADO:         return "CLASIFICADO";
    case Estado::DOSIFICANDO:         return "DOSIFICANDO";
    case Estado::FINALIZADO:          return "FINALIZADO";
    case Estado::ERROR_WIFI:          return "ERROR_WIFI";
    case Estado::ERROR_CAMARA:        return "ERROR_CAMARA";
    case Estado::ERROR_CLASIFICACION: return "ERROR_CLASIFICACION";
    case Estado::ERROR_SERVO:         return "ERROR_SERVO";
    case Estado::ERROR_ALIMENTACION:  return "ERROR_ALIMENTACION";
    case Estado::ERROR_MECANISMO:     return "ERROR_MECANISMO";
  }
  return "?";
}

const char* nombreAlerta(Alerta a) {
  switch (a) {
    case Alerta::NINGUNA:                  return "NINGUNA";
    case Alerta::COMIDA_BAJA:              return "COMIDA_BAJA";
    case Alerta::COMIDA_AGOTADA:           return "COMIDA_AGOTADA";
    case Alerta::COMIDA_REPUESTA:          return "COMIDA_REPUESTA";
    case Alerta::SENSOR_NIVEL_SIN_LECTURA: return "SENSOR_NIVEL_SIN_LECTURA";
  }
  return "?";
}

Controlador::Controlador(Hardware& hw, const Parametros& p) : hw_(hw), p_(p) {}

// ----------------------------------------------------------------------------
// Nivel de la tolva: se mide cada intervaloNivelMs (y después de cada ración),
// solo en ESPERANDO para no interferir con la dosis ni con el HC-SR04 frontal.
// Un cambio de nivel se confirma con lecturasNivel lecturas seguidas
// (las croquetas forman una superficie irregular) y tiene histéresis.
// ----------------------------------------------------------------------------
void Controlador::emitir(Alerta a) {
  logf("ALERTA %s (nivel %.0f %%)", nombreAlerta(a), nivelPct_);
  if (hw_.notificar(a, nivelPct_)) {
    pendiente_ = Alerta::NINGUNA;
  } else {
    pendiente_ = a;                 // se reintenta más tarde
    tPendiente_ = hw_.ahoraMs();
  }
}

void Controlador::vigilarNivel(uint32_t ahora) {
  if (!p_.usarSensorNivel) return;
  if (pendiente_ != Alerta::NINGUNA && ahora - tPendiente_ >= p_.reintentoAlertaMs) {
    emitir(pendiente_);
  }
  if (nivelMedido_ && ahora - tNivel_ < p_.intervaloNivelMs) return;
  nivelMedido_ = true;
  tNivel_ = ahora;

  float n = hw_.nivelTolvaPct();
  if (n < 0) {
    if (++invalidas_ >= p_.lecturasNivel && !avisoSinLectura_) {
      avisoSinLectura_ = true;
      nivelPct_ = -1.0f;              // desconocido: NO bloquea la alimentación
      emitir(Alerta::SENSOR_NIVEL_SIN_LECTURA);
    }
    return;
  }
  invalidas_ = 0;
  avisoSinLectura_ = false;
  nivelPct_ = n;

  bajas_ = (n < p_.nivelAlertaPct) ? bajas_ + 1 : 0;
  vacias_ = (n <= p_.nivelVacioPct) ? vacias_ + 1 : 0;
  noVacias_ = (n > p_.nivelVacioPct) ? noVacias_ + 1 : 0;
  altas_ = (n > p_.nivelRearmePct) ? altas_ + 1 : 0;

  if (vacias_ >= p_.lecturasNivel && alertaNivel_ != Alerta::COMIDA_AGOTADA) {
    alertaNivel_ = Alerta::COMIDA_AGOTADA;
    emitir(Alerta::COMIDA_AGOTADA);
  } else if (altas_ >= p_.lecturasNivel && alertaNivel_ != Alerta::NINGUNA) {
    alertaNivel_ = Alerta::NINGUNA;
    emitir(Alerta::COMIDA_REPUESTA);
  } else if (bajas_ >= p_.lecturasNivel && alertaNivel_ == Alerta::NINGUNA) {
    alertaNivel_ = Alerta::COMIDA_BAJA;
    emitir(Alerta::COMIDA_BAJA);
  } else if (noVacias_ >= p_.lecturasNivel && alertaNivel_ == Alerta::COMIDA_AGOTADA) {
    alertaNivel_ = Alerta::COMIDA_BAJA;   // repuesto un poco: vuelve a dispensar, sigue bajo
    emitir(Alerta::COMIDA_BAJA);
  }
}

void Controlador::logf(const char* fmt, ...) {
  char buf[160];
  va_list args;
  va_start(args, fmt);
  vsnprintf(buf, sizeof(buf), fmt, args);
  va_end(args);
  hw_.log(buf);
}

void Controlador::iniciar() {
  tEstado_ = hw_.ahoraMs();
  zonaArmada_ = true;
  if (!hw_.wifiConectado()) {
    cambiarA(Estado::ERROR_WIFI, "sin Wi-Fi al iniciar");
  } else {
    cambiarA(Estado::ESPERANDO, "sistema iniciado");
  }
}

void Controlador::cambiarA(Estado nuevo, const char* motivo) {
  logf("[%s] -> [%s]%s%s", nombreEstado(estado_), nombreEstado(nuevo),
       motivo ? " : " : "", motivo ? motivo : "");
  estado_ = nuevo;
  tEstado_ = hw_.ahoraMs();
  tUltimoReintento_ = tEstado_;
}

bool Controlador::esErrorBloqueante() const {
  // Requieren intervención humana (revisar mecánica / cableado del servo)
  return estado_ == Estado::ERROR_SERVO || estado_ == Estado::ERROR_MECANISMO;
}

bool Controlador::mascotaPresente(float d) const {
  return d >= p_.distMinCm && d <= p_.distDeteccionCm;
}

void Controlador::volverAEsperar(const char* motivo) {
  // La detección queda desarmada hasta que la zona esté libre ZONA_LIBRE_MS:
  // evita que una mascota que se queda delante dispare ciclos en bucle.
  zonaArmada_ = false;
  contandoZonaLibre_ = false;
  lecturasPresente_ = 0;
  cambiarA(Estado::ESPERANDO, motivo);
}

void Controlador::borrarErrores() {
  if (estado_ >= Estado::ERROR_WIFI) {
    volverAEsperar("errores borrados manualmente");
  }
}

// ----------------------------------------------------------------------------
// Registro de raciones (ventana móvil de 24 h, sin reloj de tiempo real)
// ----------------------------------------------------------------------------
void Controlador::registrarRacion(int clase) {
  uint32_t ahora = hw_.ahoraMs();
  registro_[clase][posRegistro_[clase]] = ahora;
  posRegistro_[clase] = (posRegistro_[clase] + 1) % REGISTRO;
  if (nRegistro_[clase] < REGISTRO) nRegistro_[clase]++;
  totales_[clase]++;
  huboRacion_ = true;
  tUltimaRacion_ = ahora;
}

uint8_t Controlador::racionesUltimas24h(int clase) const {
  if (clase < 1 || clase > 2) return 0;
  uint32_t ahora = hw_.ahoraMs();
  uint8_t n = 0;
  for (uint8_t i = 0; i < nRegistro_[clase]; i++) {
    if (ahora - registro_[clase][i] < MS_24H) n++;  // resta sin signo: tolera desborde de millis()
  }
  return n;
}

uint32_t Controlador::cooldownRestanteMs() const {
  if (!huboRacion_) return 0;
  uint32_t trans = hw_.ahoraMs() - tUltimaRacion_;
  return trans >= p_.cooldownGlobalMs ? 0 : p_.cooldownGlobalMs - trans;
}
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

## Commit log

2026-10-01 Dispensador IoT: firmware, visión, STL paramétricos y esquema eléctrico
    - ESP32: máquina de estados (probada en PC), HC-SR04, MG995 con rampa y
    anti-atasco, monitoreo de energía, cliente HTTP y /status.
    - ESP32-CAM: captura JPEG por HTTP (/capture, /status).
    - OpenCV: servidor de clasificación PERRO/GATO con MobileNetV2 (cv2.dnn),
    control de calidad de imagen, simulador de cámara y pruebas.
    - Mecánica: generador paramétrico de 19 piezas STL con verificación de
    interferencias, recorrido del alimento e imprimibilidad.
    - Documentación: esquema de conexiones, balance energético y calibración.
    Claude-Session: https://clau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
    [00_Ensamblaje_Referencia_NO_IMPRIMIR.stl, 01_Base_Torre.stl, 02_Cuerpo_Principal.stl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]
2026-10-01 README: documento técnico completo en el orden solicitado
    Auditoría de arquitectura, eléctrica, energética, de comunicación, de
    visión y mecánica; pines y conexiones; API; máquina de estados;
    dosificación y calibración; plan de pruebas; fallos y soluciones; lista
    de verificación y auditoría final con lo verificado y lo pendiente de
    prueba física.
    Claude-Session: https://claude.ai/code/session_016inkwYuFtHC45Quj8Md6GU
2026-10-01 Firmware compilado con Espressif y probado en QEMU; correcciones y CI
    Verificación:
    - Ambos firmwares compilan con la cadena oficial (núcleos 2.0.17 y 3.0.7).
    - Variante -DSIMULACION_QEMU (solo sustituye Wi-Fi y ADC) con autoprueba
    en setup(); qemu_autoprueba.sh arranca el firmware real en el emulador
    de Espressif y verifica 12 puntos.
    - Prueba del modelo real con 25 imágenes públicas (perros, gatos y
    animales parecidos): 0 decisiones peligrosas.
    - Workflow de GitHub Actions: Python, STL, máquina de estados, compilación
    real en ambos núcleos y autoprueba en QEMU.
    Correcciones:
    - Botón BOOT: una pulsación larga = un solo borrado de errores (antes,
    mantenido, borraba cada 5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
    [Dispensador_ESP32.ino, Energia.cpp, Red.cpp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]
2026-10-01 Placa de control con verificación, arnés de cables y arreglo del CI de QEMU
    - Documentation/wiring/generar_placa_control.py: disposición de la placa
    perforada 90x70 (SVG/PNG) y lista de 27 cables numerados. Verifica que
    cada red quede unida, que ningún cable pase sobre otro agujero, que los
    GPIO coincidan con config.h, que no se usen pines prohibidos y que el
    divisor del ECHO deje <= 3,4 V. Se ejecuta en GitHub Actions.
    - Arnés de cables con conductores, sección y longitudes estimadas sobre
    el modelo 3D.
    - CI: el job de QEMU necesitaba libsdl2 en el runner; esptool fijado a
    4.8.1; el script informa claramente si QEMU no puede ejecutarse.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
    [generar_placa_control.py]
2026-10-01 Lista de materiales (CSV) y recuento coherente de condensadores
    - Documentation/components/lista_materiales.csv con cantidades.
    - 470 uF: son 3 (salida del Buck B, placa de control y ESP32-CAM).
    - Filtros de 100 nF de los ADC: junto al ESP32 (placa de control), igual
    en el esquema general y en la placa.
    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
    [lista_materiales.csv]
2026-10-01 Sensor de nivel en la tolva, estación solar remota y piezas para Neptune 4 Plus
    Recomendaciones del profesor:
    - Segundo HC-SR04 en la tapa de la tolva (cápsula 13b colgada de 13a, tapa 13c)
    con alertas COMIDA_BAJA / COMIDA_AGOTADA / COMIDA_REPUESTA al PC (POST /alerta),
    panel web y aviso opcional al celular (ntfy). El nivel se expresa en % de
    VOLUMEN con una tabla calculada del embudo (NivelGeometria.h), verificada
    por generar_stl.py.
    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
    [00_Ensamblaje_Referencia_NO_IMPRIMIR.stl, 07_Tolva.stl, 09_Conducto_Alimento.stl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]
2026-10-01 Documentación actualizada: README, BOM, energía, OpenCV y ESP32
    - README: recomendaciones del profesor (estación solar remota y sensor de
    nivel) en resumen, componentes, arquitectura, flujo, API (/alerta, panel
    web, ntfy), pines GPIO19/21, §18.1 sensor de nivel, §21 estación solar,
    máquina de estados, errores, piezas 12a/12b/13a/13b/13c, impresión en la
    Neptune 4 Plus, archivos, pruebas y auditoría.
    - Lista de materiales: 2 × HC-SR04, R5/R6, GX12, cables, tornillería M4,
    filamento según el laminado.
    - calculo_energia.py: segundo HC-SR04 y caída en el cable del panel remoto.
    - servidor_vision.py: opciones --esp32 y --ntfy; /alerta responde 400 ante
    JSON con otra forma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
    [lista_materiales.csv]
2026-10-02 Fotos cada 2 s en vez de video y funcionamiento 100 % local
    Ideas/preguntas del profesor:
    - Fotos en vez de grabar: la ESP32-CAM pasa a modo foto (un búfer,
    CAMERA_GRAB_WHEN_EMPTY: no captura cuadros de forma continua). Con la
    mascota delante, el ESP32 pide una foto cada 2 s hasta identificarla
    (máx. 5 por visita) y no repite el /status de la cámara en las fotos
    siguientes. El PC toma 1 foto por pedido y promedia las fotos de la misma
    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
2026-10-02 README: recuento de escenarios actualizado (26)
    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
2026-10-03 Fuentes del video de funcionamiento y armado
    - guion.py: 29 escenas con la narración (texto de subtítulos + pronunciación).
    - hacer_audio.py: narración con voz neuronal sin conexión (Piper es_MX vía
    sherpa-onnx) y tiempos de cada frase.
    - web/escena3d.html + render3d.mjs: animaciones 3D (portada, dosificador
    con la croqueta en corte, estación solar y los pasos del armado).
    - web/laminas.html + laminas.py + render_laminas.mjs: láminas explicativas.
    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
2026-10-03 Video de funcionamiento y armado (6:42, narrado y subtitulado)
    - Documentation/video/Dispensador_IoT_funcionamiento_y_armado.mp4:
    1280x720, 25 fps, H.264 + AAC, -16 LUFS, subtítulos incrustados; 29
    escenas: qué hace, componentes, funcionamiento, fotos cada 2 s, red
    local, dosificador animado en corte, recorrido del alimento, sensor de
    nivel y panel web, energía y estación solar, esquema y placa, impresión
    y los 11 pasos del armado animados.
    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
2026-11-09 docs: documentar auditoría inicial de integración IoT local
2026-11-12 feat: backend local, dashboard en tiempo real y documentación USB-C
    - Backend (stdlib + SQLite): telemetría y alertas del ESP32, descubrimiento UDP,
    proxy MJPEG, galería con nombres validados, historial persistente, SSE,
    dispensación con token, confirmación y límite de frecuencia.
    - Dashboard: panel, cámara, galería, control con confirmación e historial.
    - Firmware ESP32: telemetría, token, descubrimiento y pruebas de lógica ampliadas.
    - ESP32-CAM: /status con resolución e IP; corrige el límite del flujo MJPEG.
    - Docs: conexiones USB-C (sin solar ni fusible), arquitectura, pruebas
    simuladas vs. físicas. 24 pruebas de backend; ambos firmwares compilan
    con arduino-cli. Ha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
2026-11-14 docs: aclarar alcance funcional del dashboard y sensores
2026-11-14 docs: marcar cableado heredado como obsoleto
2026-11-14 docs: rehacer README para configuración vigente sin solar
2026-11-14 docs: actualizar guía ESP32 a un sensor y control manual
2026-11-14 docs: reemplazar plan de impresión para prototipo USB-C
2026-11-14 fix: corregir referencias y comentario de hardware activo
2026-11-14 docs: actualizar auditoria de integracion USB-C
2026-11-14 docs: advertir que video corresponde a version solar anterior
2026-11-14 docs: agregar manual de instrucciones de conexiones
2026-11-14 docs: enlazar manual de conexiones desde README
